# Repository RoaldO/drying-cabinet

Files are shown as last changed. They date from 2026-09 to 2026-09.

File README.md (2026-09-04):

# clean-air-cabinet

A clean-air cabinet for airbrushed / freshly painted workpieces: an ESP32-driven
extraction fan pulling through a printed duct and foam filter, controlled from
Home Assistant.

One project, three disciplines:

| Folder | What | Tooling |
|---|---|---|
| `cad/` | Parametric fan duct, filter enclosure, finger-guard grill, dust cover, gaskets | build123d (uv), exported as STL/3MF |
| `pcb/` | Carrier board for the ESP32 fan controller — 12 V in, PTC polyfuse, Recom R-78B5.0 buck to 5 V | KiCad |
| `firmware/` | Fan on/off + PWM speed + tach RPM readback, native HA API | ESPHome |

See `docs/2026-08-22-cleanaircabinet-design.md` for the full electronics design
(wiring, GPIO assignment, assumptions) and `cad/` for the material rationale
(PETG over PETG-CF).

## Physical build status (2026-08-28)

Printed and assembled onto a repurposed storage bin; fan runs quietly at ~30–35 %.
Firmware MVP works (on/off + speed from HA, RPM readback). Environmental sensors
deferred — solvent vapour and paint aerosol degrade the candidate sensors.

## Firmware setup

```bash
cd firmware
just secrets                 # sops -d secrets.enc.yaml > secrets.yaml
esphome run cleanaircabinet.yaml   # first flash over USB, then OTA
```

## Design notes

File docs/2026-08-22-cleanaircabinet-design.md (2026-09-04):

# Clean Air Cabinet — ESP32 Fan Controller Design

Datum: 2026-08-22

## Doel

Aansturing van een clean air cabinet voor geverfde werkstukken: fan aan/uit en snelheid
regelen, uitlezen/bedienen via Home Assistant. Later uit te breiden met temperatuur,
relatieve luchtvochtigheid en luchtkwaliteit sensoren (lagere prio, niet in MVP).

## Architectuur

ESPHome firmware op de ESP32, verbonden via WiFi. Home Assistant integratie via de
ESPHome native API (encrypted, auto-discovery) — geen MQTT-broker nodig.

## Hardware

- **MCU**: AZDelivery ESP-32 Dev Kit C V4 — ESP32-WROOM-32 module, 512KB RAM.
  ESPHome board type: `esp32dev`.
- **Fan**: Arctic P8 Max, 4-pin PWM (GND, 12V, PWM-in, Tach-out).
- **Voeding**: één 12V-bron voedt alles. Generieke laptopvoeding 12.25V/1A (gemeten, zakt
  onbelast/belast nauwelijks: 12.25V → 12.22V). Vanaf de brick: PTC-polyfuse in de +12V-lijn
  vóór het splitspunt (**Bourns MF-R110**: 1.1A hold / 2.2A trip, 30V, radiaal THT — soldeert
  direct op de print, herstelt na afkoelen). Daarna splitsen naar (a) de fan rechtstreeks
  op 12V en (b) een step-down naar 5V voor de ESP32. Steady-state ~0.45A (fan ~0.2A + buck-in
  ~0.25A), ruim onder de hold-stroom.
  - Step-down: **Recom R-78B5.0-1.5** (7805-pinout, gesealed, kortsluit- + thermische
    beveiliging, in 6.5–18VDC, uit 5V/1.5A). 12.25V-brick zit ruim binnen bereik. Geen
    trimpot om verkeerd te zetten. 5V-uitgang naar de ESP32 `5V`/`VIN`-pin; de onboard
    AMS1117 maakt daar 3.3V van. Meer marge nodig (andere brick later)? R-78B5.0-2.0 —
    2A én 6.5–32V in, zelfde SIP3-footprint.
  - Historie: eerdere opzet was gescheiden voedingen (ESP32 op USB, fan op 12V) omdat de
    breadboard-PSU 15V/9V/5V bleek te geven i.p.v. 12V. Sensoren zijn uitgesteld (zie
    Buiten scope), dus een gescheiden 5V-tak voor sensoren is niet meer nodig en de opzet
    gaat terug naar één voeding.
  - **USB-flashen**: het board heeft geen scheidingsdiode tussen USB-5V en de 5V-pin.
    OTA is draadloos en dus geen probleem; bij een USB-flash eerst de buck-5V loskoppelen
    zodat twee 5V-bronnen niet tegen elkaar werken.
  - Bestellen (beide bij TME, geen minimum orderbedrag):
    - R-78B5.0-1.5: <https://www.tme.eu/en/details/r-78b5.0-1.5/dc-dc-converters/recom/>
    - MF-R110: <https://www.tme.eu/en/details/mf-r110/tht-polymer-fuses/bourns/>

## Bekabeling

| Signaal | Van | Naar | Opmerking |
|---|---|---|---|
| 12V brick + | brick | MF-R110 → splitspunt | PTC-polyfuse Bourns MF-R110 in de +12V-lijn vóór het splitspunt |
| Fan 12V+ / GND | splitspunt | Fan | Rechtstreeks, niet via ESP32 |
| Buck in | splitspunt | Recom R-78B5.0-1.5 (Vin) | 12V |
| Buck uit | Recom R-78B5.0-1.5 (Vout) | ESP32 `5V`/`VIN`-pin | 5V; onboard AMS1117 maakt 3.3V |
| Fan PWM-in | ESP32 GPIO18 | Fan | LEDC output, 25kHz |
| Fan Tach-out | Fan | ESP32 GPIO19 | Open-collector, interne pull-up in ESPHome |
| GND | brick − | fan GND, buck GND, ESP32 GND | Eén gemeenschappelijke massa |

GPIO25/26 (oorspronkelijk gepland) zaten fysiek onbereikbaar op de breadboard-opstelling
(board is bijna zo breed als de breadboard, alleen één pinrij is bereikbaar). Op die
bereikbare rij: **CLK, D0, D1, CMD zijn de interne SPI-flash pins (GPIO6/7/8/11) — nooit
gebruiken**, en RX/TX zijn de USB-serial pins — ook vermijden. GPIO2/15 zijn
boot-strapping pins, kunnen wel maar liever vermeden. Vrije bruikbare pins op die rij:
4, 16, 17, 5, 18, 19, 21, 22, 23 — GPIO18 (PWM) en GPIO19 (tach) gekozen.

**Bevestigd (POC breadboard test)**: 3.3V ESP32-logic stuurt de fan's PWM-ingang prima
aan, geen level-shifter nodig. On/off en variabele snelheid werken beide via HA. Tach
geeft ~5000 RPM op volle snelheid, consistent met de Arctic P8 MAX-datasheet (de
high-speed variant, i.t.t. de ~2000 RPM standaard P8).

## Home Assistant integratie

Native API. Verwachte entities:
- `fan.cleanaircabinet` — on/off + snelheid (%)
- `sensor.cleanaircabinet_fan_speed` — RPM (afgeleid van tach-pulsen, 2 pulsen/omwenteling
  aangenomen — standaard voor de meeste PC/case fans)

WiFi-credentials, API encryption key en OTA-wachtwoord staan in `secrets.yaml`
(gitignored). Template: `secrets.yaml.example`.

## Repo structuur

```
cleanaircabinet/
  cleanaircabinet.yaml       # ESPHome config
  secrets.yaml.example       # template
  secrets.yaml                # gitignored, echte waarden
  .gitignore
  README.md
  docs/superpowers/specs/     # dit document
```

## Testen

1. Eerste flash via USB: `esphome run cleanaircabinet.yaml`.
2. Verifiëren dat het device in Home Assistant verschijnt (ESPHome discovery).
3. Fan speed control testen (0–100%).
4. Tacho-sensor testen: RPM-waarde plausibel vergelijken met Arctic P8 Max datasheet
   (typisch 200–2200 RPM range).
5. Daarna OTA-updates voor verdere iteratie.

## Buiten scope (later, lagere prio)

- Temperatuur/RH-sensor (bv. SHT4x, I2C)
- Luchtkwaliteitssensor: stofdeeltjes (PMS5003, UART — 3.3V-logic, geen level-shifter) en
  eventueel VOC/oplosmiddelen (SGP40, I2C)
- Lokale fysieke bediening (knop/potmeter op de cabinet) — nu bewust MVP-only via HA

### Waarom sensoren nog uitgesteld zijn

De cabine droogt geverfde en soms gelijmde onderdelen; de lucht bevat oplosmiddel-damp en
tijdens de beginfase verf-aerosol. Dat is een probleem voor elke voorgestelde sensor:

- **RH (SHT4x)**: polymeer-vochtsensoren driften door VOC-blootstelling. SHT4x herstelt
  grotendeels (reversibel + bake-procedure), maar aanhoudende damp degradeert 'm. Vereist
  de PTFE-membraanversie en montage buiten de directe overspray.
- **VOC (SGP40)**: geeft een adaptieve VOC-index (0–500), geen absolute waarde — het
  algoritme her-ijkt naar ~100, dus het meet veranderingen, niet "damp nog aanwezig
  ja/nee". Het MOX-element wordt bovendien permanent vergiftigd door silicoenen (mogelijk
  in lijm/kit). Operating range 0–50°C.
- **PM (PMS5003 / SPS30)**: verf-aerosol slibt de optische kamer en de interne fan dicht.
  Levensduur wordt dan een slijtdeel. Duty-cyclen via de sleep-pin en alleen ná een purge
  meten, of filteren.

Randvoorwaarde die dit oplost: elektronica en sensoren **buiten** de cabine monteren met
alleen gefilterde meetpunten naar binnen — dat dekt meteen het temp-bereik van de SGP40 en
condensatie op de PCB's. Wordt uitgewerkt in een aparte iteratie met eigen review; open
vragen: wordt de cabine verwarmd (en hoe warm), watergedragen of oplosmiddel-verf, en
silicone-houdende lijm ja/nee.

Toevoeging gebeurt als extra ESPHome componenten in dezelfde YAML: I2C-bus op GPIO21/22
(SHT4x 0x44 + SGP40 0x59), PMS5003 op UART1 (RX GPIO16, optioneel TX GPIO17). Sensoren van
de 5V-rail voeden, niet van de 3V3-pin.

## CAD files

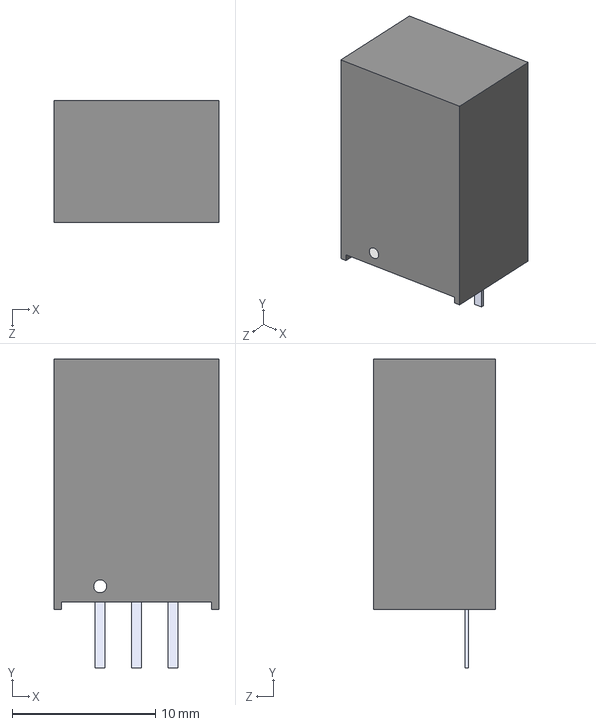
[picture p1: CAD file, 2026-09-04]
pcb/R-78B5.0-1.5.step
11.5 x 21.6 x 8.50 mm

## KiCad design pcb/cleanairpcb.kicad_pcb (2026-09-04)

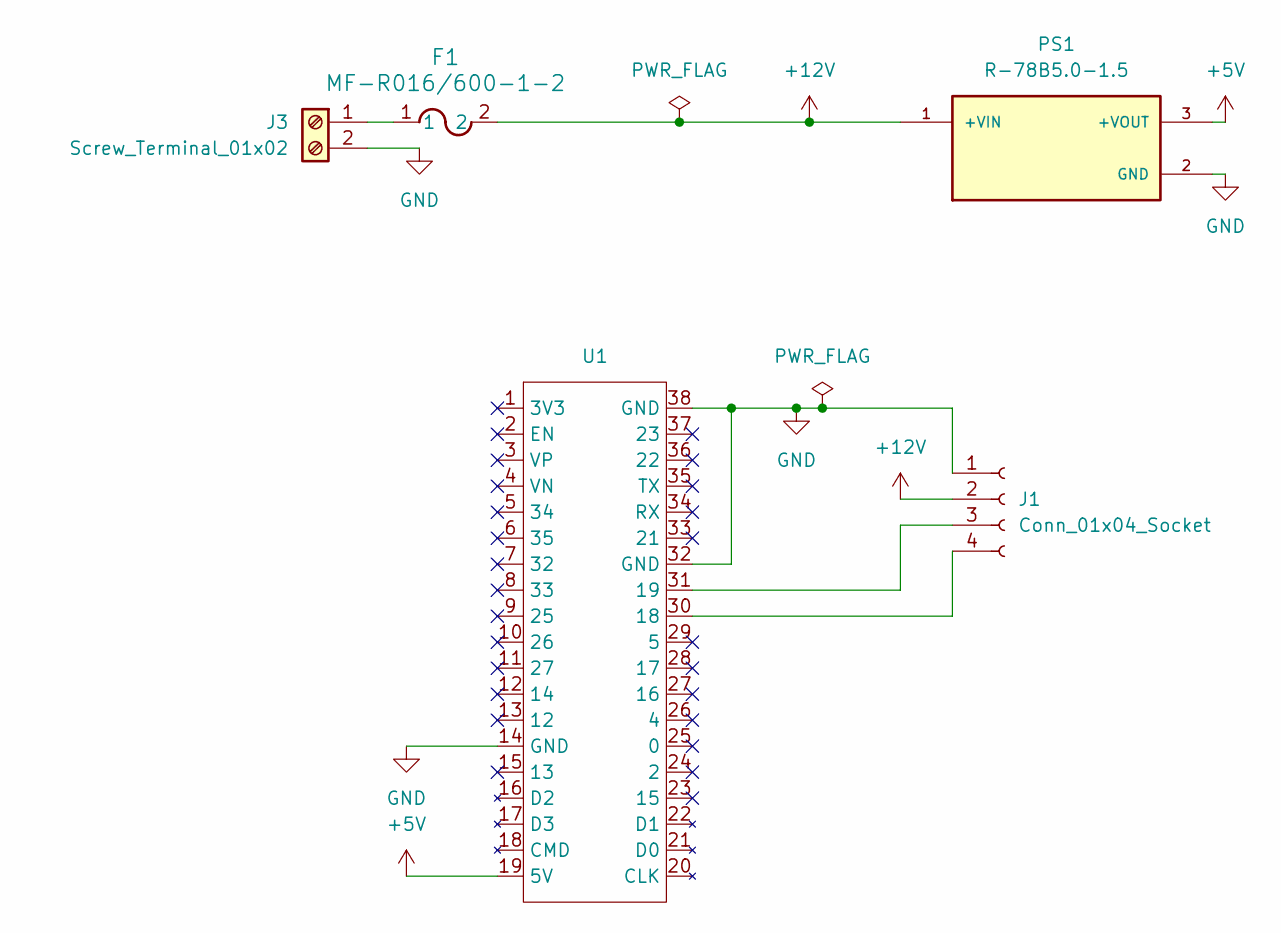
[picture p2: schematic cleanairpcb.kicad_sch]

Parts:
F1: MF-R016/600-1-2; FUSE_MFR16_16X6_BRN
J1: Conn_01x04_Socket; JST_XH_B4B-XH-A_1x04_P2.50mm_Vertical
J3: Screw_Terminal_01x02; TerminalBlock_Phoenix_MPT-0,5-2-2.54_1x02_P2.54mm_Horizontal
PS1: R-78B5.0-1.5; SIP3_11.6x8.5mm; PARTREV 4
U1: ESP32_DevKitC_V4

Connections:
+5V: PS1.3 (+VOUT), U1.19 (5V)
+12V: F1.2, J1.2, PS1.1 (+VIN)
GND: J1.1, J3.2, PS1.2 (GND), U1.14 (GND), U1.32 (GND), U1.38 (GND)
unnamed: J1.3, U1.31 (19)
unnamed: J1.4, U1.30 (18)
unnamed: F1.1, J3.1

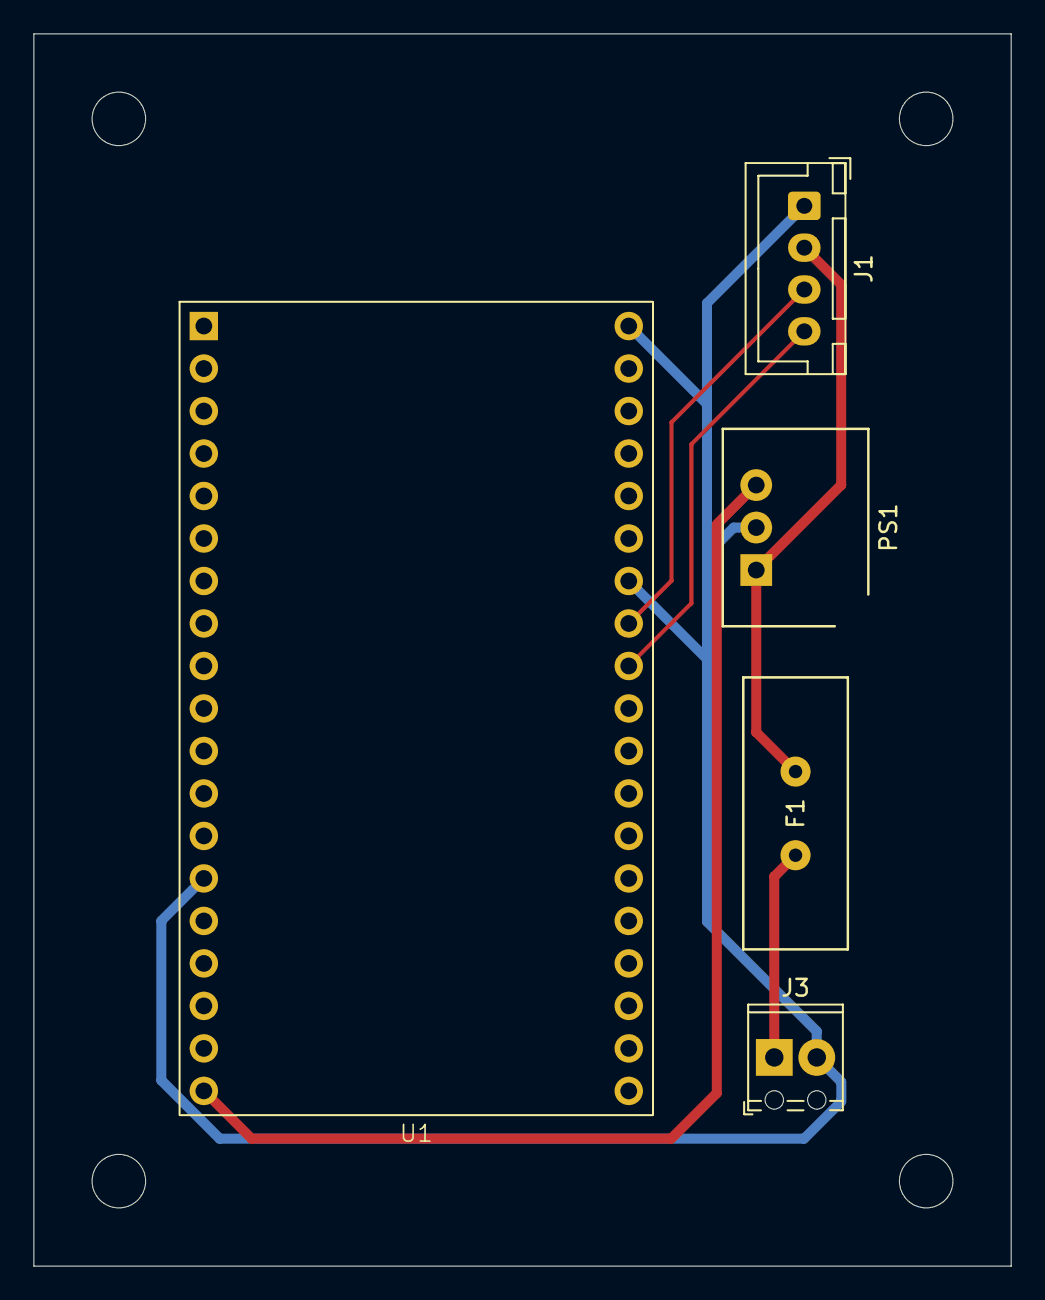
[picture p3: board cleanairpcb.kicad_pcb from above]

Board: 2 copper layers, 58.4 x 73.7 mm, 5 parts (0 on the bottom side), 6 nets.

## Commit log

2026-08-22 Init ESPHome project for clean air cabinet fan controller
    ESP32 (esp32dev) drives Arctic P8 Max PWM fan via LEDC + tach RPM
    feedback, exposed to Home Assistant through ESPHome's native API.
    Design spec in docs/superpowers/specs/.
2026-08-22 Move fan GPIOs off breadboard-blocked pins, throttle RPM publish rate
    GPIO25/26 were physically unreachable on the breadboard (board nearly
    as wide as the breadboard); moved PWM/tach to GPIO18/19. Also switched
    esp32 framework to esp-idf (arduino no longer supported by ESPHome for
    esp32dev). pulse_meter has no update_interval option — it's event
    driven — so added a throttle filter instead to stop flooding HA with a
    new RPM state on every pulse (~166/s at full speed).
    Breadboard POC confirmed working end-to-end: on/off, variable speed,
    and RPM readback all correct via Home Assistant.
2026-08-26 Initial project setup with uv and build123d
    uv-managed Python project with build123d as CAD dependency; main.py
    exports a placeholder Box to verify the toolchain works end to end.
2026-08-26 Add ocp_vscode live preview
    Push the model to the ocp_vscode viewer on run for interactive
    preview alongside the STL export.
2026-08-26 Add fan duct flange profile (2D)
    Parameterized rounded-corner flange outline: inner_x/inner_y (80mm),
    border_width (10mm), outer_radius (5mm). Reusable as flange_profile()
    for the duct base and other flanged parts.
2026-08-26 Add screw holes to flange profile
    hole_diameter (default 3.2mm, M3) and holes_per_side (default 3) are
    now parameters, so the profile can be reused with other fastener
    sizes/counts. Holes are centered in equal segments along each side's
    straight run rather than anchored at the ends, so they don't cluster
    or overlap near the rounded corners.
2026-08-26 Extrude flange, add duct, fix hole centering under duct wall
    - flange(): extrudes flange_profile() by a thickness parameter,
    defaulting to DEFAULT_WALL_THICKNESS.
    - duct(): rectangular tube whose inner opening matches inner_x/inner_y
    exactly, height as a parameter (default 5mm).
    - fan_duct(): stacks duct() on top of flange() so the duct's bottom
    sits on the flange's top face and its inside aligns with the
    flange's inside.
    - flange_profile()/flange() gain hole_outward_offset (default 0): the
    duct wall covers part of the border's inner edge on the top face, so
    fan_duct() shifts the holes outward by duct_wall_thickness/2 to keep
    them centered on the strip actually visible from the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
2026-08-26 Add vent profile with reusable rounded_square shape
    vent_profile(): 8.5x8.5cm rounded square (5mm corner radius) with a
    parametrized 7cm circular hole. The outer rounded-square outline is
    split into rounded_square(width, corner_radius) since it'll be reused
    by other parts later.
2026-08-26 Loft the duct-to-vent transition into a continuous solid
    duct_transition() lofts the duct's cross-section up to vent_profile()
    over `height` (the 2cm gap), producing a tapered hollow connector
    instead of a disconnected floating vent shape. duct_with_vent() now
    returns one continuous Part: flange + duct + transition.
2026-08-26 Add M3 heat-insert plate on top of the transition
    heat_insert_plate() extrudes the vent's rounded-square profile by
    heat_insert_depth (default 5mm), removing the central vent hole plus
    one M3 heat-insert hole per corner (5 cylinders total). Corner hole
    position is parametrized as a radial distance from center
    (heat_insert_corner_distance), defaulted to 40mm so the insert holes
    clear the 70mm vent hole instead of overlapping it. Stacked on top of
    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
2026-08-26 Add rounded-square rim wall on top of the heat-insert plate
    rounded_square_wall() reuses rounded_square() and insets it via
    offset() by wall_thickness (default DEFAULT_WALL_THICKNESS) to build
    the inner boundary, then extrudes the resulting ring by height
    (default 10mm). Stacked on top of heat_insert_plate() in
    duct_with_vent() via rim_wall_thickness/rim_height.
2026-08-26 Pin rim's inner size and derive vent/plate outer size from it
    rounded_square_wall() now takes inner_width (pinned, default 80mm) and
    derives outer_width = inner_width + 2*wall_thickness, so adding wall
    thickness grows the outer boundary instead of shrinking the inner one.
    duct_with_vent() drops vent_outer_width as an independent parameter:
    it's now computed from the rim's own geometry
    (rim_inner_width + 2*rim_wall_thickness), so the vent profile,
    transition top, and heat-insert plate automatically match the rim's
    outer footprint instead of drifting out of sync with it.
2026-08-26 Pin fan-spec dimensions and add protector grill part
    - Vent hole diameter set to 76mm across vent_profile/duct_transition/
    heat_insert_plate/duct_with_vent.
    - Heat-insert corner distance set to 101.6/2mm (standard fan mounting
    hole spacing) instead of the arbitrary 40mm default.
    - New protector_grill(): rounded-square base shape matching the duct's
    top outer boundary, with the 76mm vent hole and 4 corner M3 bolt
    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
2026-08-26 Add finger-guard bars to the protector grill
    finger_guard_bars() tiles parallel bars across the vent circle
    (bar_width default DEFAULT_WALL_THICKNESS, bar_gap default 6mm as a
    child-safety rule of thumb to verify against the actual applicable
    standard). Straight bars in one direction keep the part flat and
    overhang-free to print while leaving most of the opening clear for
    airflow. protector_grill() now extrudes the full profile into a Part.
2026-08-26 Add grill perimeter wall, dust cover, and full assembly preview
    - protector_grill() gains a perimeter wall on top of its plate (in
    print direction), reusing rounded_square_wall() sized to match the
    grill's own outer edge.
    - dust_cover(): plate + perimeter wall reusing the same base shape as
    protector_grill(), but fully solid (no vent hole, no finger-guard
    bars, no bolt holes) and scaled up so fit_over_width becomes its
    inside dimension (plus fit_margin clearance) instead of its outside
    one, so it slips over the duct/grill assembly to keep dust out when
    the fan is idle.
    - Bottom of the script now renders the full assembly: duct_with_vent()
    (gray), protector_grill() (orange), a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
2026-08-26 Add filter_enclosure with ventilated, sealed support base
    Printed in its natural (regular) orientation. The section below
    base_offset is the filter's support base: a rounded rectangle matching
    the flange's outer shape, with the border solid (seals against the
    walls above so air can't bypass the filter along the sides) and the
    inner opening spanned by sparse support_ribs() instead of a solid
    plate, so the filter is held up without blocking much airflow. A short
    seal_lip stands at the inner_x/inner_y boundary to block air sneaking
    sideways between the filter's edge and the border. Above base_offset,
    the duct flange's 2D shape (with M3 heat-insert holes) is extruded
    upward by filter_thickness (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
2026-08-26 Switch filter support ribs to a crossed grid
    Single-direction bars leave long open channels that can jet air
    through in streaks, which risks uneven flow reaching the airbrush
    subject downstream of the filter. Crossing ribs in both X and Y
    spreads the blockage evenly across the area instead.
2026-08-26 Document material choice: PETG over PETG-CF
    Recorded so it's not re-litigated later: thin features (finger-guard
    bars, support ribs, snap-fit walls) favor PETG's toughness over
    PETG-CF's stiffness, and nothing here is structurally loaded enough to
    need CF reinforcement.
2026-08-27 Add 1mm fan clearance and full 4-part assembly preview
    Fan margins were too tight. Bumping rim_inner_width to 81mm in
    duct_with_vent() cascades automatically through the already-derived
    vent_outer_width (transition top, heat-insert plate, rim all follow).
    protector_grill()'s width and dust_cover()'s fit_over_width bumped to
    85mm to match the rim's new outer size, propagating outward through
    each part's own derived dimensions.
    Bottom of the script now renders all 4 parts stacked with visual gaps:
    filter_enclosure (green) -> duct_with_vent (gray) -> protector_grill
    (orange) -> dust_cover (blue).
2026-08-27 Add flange cutting template and insert it into the assembly preview
    flange_cutting_template() reuses flange() for marking the flange's
    outline and screw holes onto an enclosure wall (e.g. the airbrush
    cabinet), matching the real mounted flange's shape, screw-hole
    positions (including the duct-wall offset), and thickness. Inserted
    into the 5-part assembly preview between the filter enclosure and the
    duct.
2026-08-27 Docs: single 12V supply, defer sensors over solvent exposure
    Power moves back to one 12V brick: Bourns MF-R110 PTC polyfuse in the
    +12V line, split to the fan (direct) and a Recom R-78B5.0-1.5 step-down
    feeding the ESP32 5V pin. The separate USB/12V supplies were only needed
    for a sensor 5V branch that is no longer planned.
    Sensors (temp/RH/PM/VOC) are deferred: solvent vapour and paint aerosol
    degrade every candidate (RH drift, MOX poisoning by silicones, optical
    fouling). Unblock needs electronics outside the cabinet with filtered
    sample points; captured as open questions in the spec.
2026-08-27 Docs: correct R-78B5.0-1.5 input range, add TME order links
    The 1.5A variant is 6.5-18VDC in (not 32V; that's the 1.0/2.0 variants).
    The 12.25V brick sits well within range. Note R-78B5.0-2.0 as the
    higher-margin alternative and add TME product links for both parts.
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2026-09-03 Add KiCad PCB: carrier board for the ESP32 fan controller
    2-layer through-hole carrier for the socketed AZDelivery ESP32-DevKitC:
    - 12V screw-terminal input, PTC-fused, split to the fan and a Recom
    R-78B5.0-1.5 step-down feeding the dev board's 5V pin
    - JST-XH header for the 4-pin fan (12V, GND, tach->GPIO19, PWM->GPIO18)
    - 2x 1x19 female headers for the dev board, antenna end overhanging with
    a copper keep-out
    - DRC clean
    Custom footprints: socketed DevKitC (2x19 THT), SIP3 regulator (hole/pad
    widened from stock), radial PTC fuse.
    Note: sym-lib-table / fp-lib-table reference the loose symbol and
    footprint files by absolute path, so the project is not yet portable
    across machines.
    Co-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
    [R-78B5.0-1.5.step, cleanairpcb.kicad_pcb, cleanairpcb.kicad_sch]
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2026-09-04 Sort merged files into firmware/, pcb/, docs/
    - firmware/: cleanaircabinet.yaml, secrets.yaml.example
    - pcb/: KiCad project flattened out of docs/kicad/cleanairpcb/, shared
    symbol/footprint libs consolidated alongside it
    - pcb/fp-lib-table, pcb/sym-lib-table: absolute /home/roald/... URIs rewritten
    to ${KIPRJMOD}-relative
    - docs/: design spec flattened out of docs/superpowers/specs/
    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
    [R-78B5.0-1.5.step, cleanairpcb.kicad_pcb, cleanairpcb.kicad_sch]
